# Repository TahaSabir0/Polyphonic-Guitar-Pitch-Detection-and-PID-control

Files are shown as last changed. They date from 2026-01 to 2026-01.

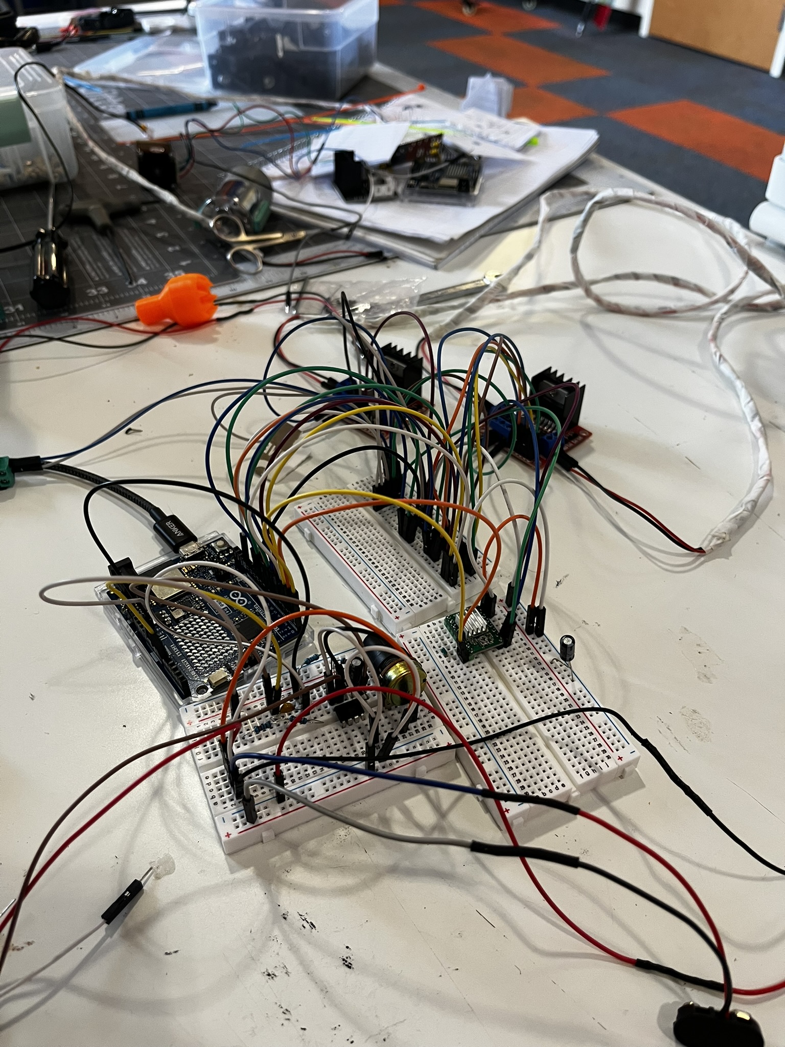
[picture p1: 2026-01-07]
hardware/system_wiring/system_wiring_1.JPEG

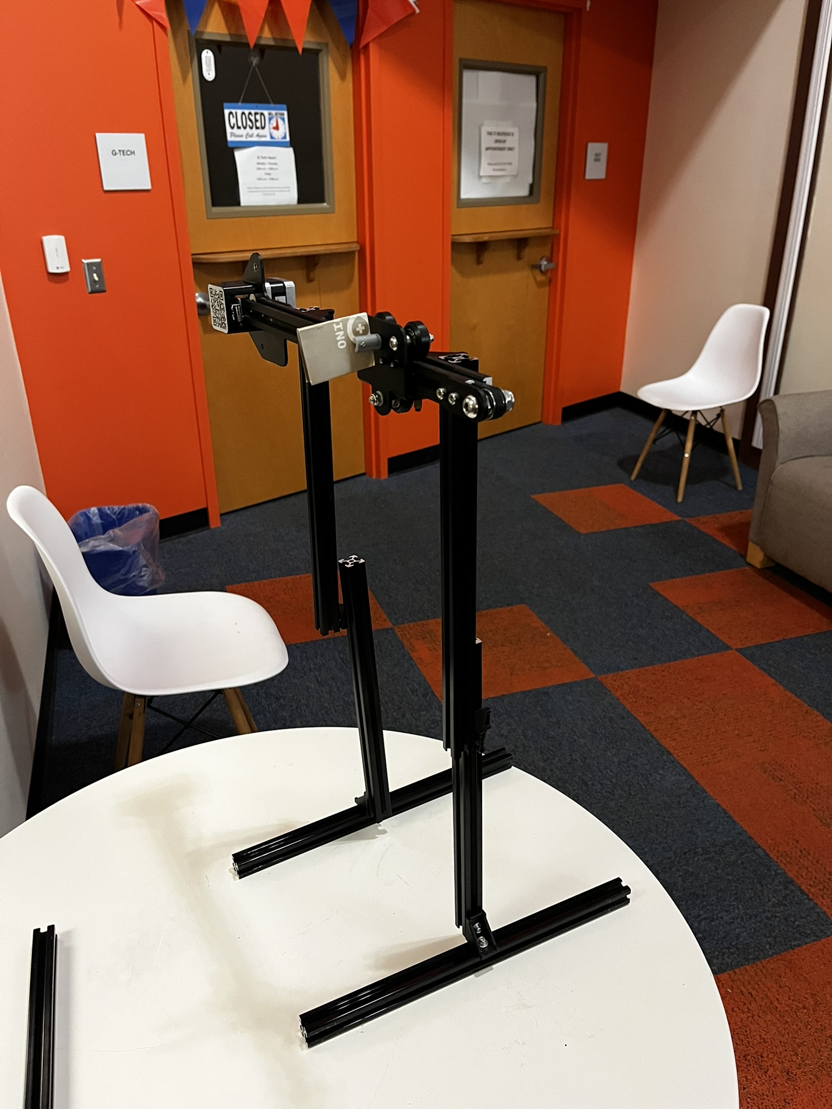
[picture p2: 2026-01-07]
hardware/individual_parts/guitar_strummer.JPEG

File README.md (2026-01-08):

# Automatic Guitar Tuning Stand

A standalone robotic system that automatically detects pitch and tunes guitar strings with precision. This project combines digital signal processing, motor control, and custom mechanical design to create a practical tool for musicians.

**Author:** Taha Sabir
**Institution:** Gettysburg College
**Program:** Digital Technology Summer Fellowship (DTSF) 2025

Watch the Demo (https://www.youtube.com/watch?v=YejNIvxSDlA)

**[▶️ Watch the Full Demo Video](https://www.youtube.com/watch?v=YejNIvxSDlA)**

---

## Table of Contents

- [Introduction](#introduction)
- [Hardware & Circuits](#hardware--circuits)
  - [Audio Detection Circuit](#1-audio-detection-circuit)
  - [Automatic Strummer](#2-automatic-strummer)
  - [Motor Selection & Tuning Mechanisms](#3-motor-selection--tuning-mechanisms)
- [Software](#software)
  - [FFT-Based Pitch Detection](#fft-based-pitch-detection)
  - [PID Control System](#pid-control-system)
  - [Code Overview](#code-overview)
- [Getting Started](#getting-started)
- [Future Improvements](#future-improvements)
- [Acknowledgements](#acknowledgements)
- [References](#references)

---

## Introduction

This repository is the guide I wish I had while building this project. Whether you're looking to replicate this automatic guitar tuning stand or create something even better, I'll walk you through every component, circuit, and line of code that makes it work.

The system consists of three fundamental subsystems working together:

1. **Audio Detection** - Captures and analyzes string vibrations to determine pitch
2. **Tuning Mechanisms** - DC motors that physically turn the tuning pegs
3. **Automatic Strummer** - A motorized slider that strums strings for polyphonic tuning

Depending on your goals, you can build any combination of these systems. Want just pitch detection? Build the audio circuit. Need a single-string tuner? Add one motor. This modular design lets you scale the project to your needs.

---

## Hardware & Circuits

### 1. Audio Detection Circuit

The audio detection system is the foundation of the project. It captures string vibrations and amplifies them for the Arduino to analyze.

#### Components

- **Microphone:** [Korg CM200BK](https://www.korg.com/us/products/tuners/cm_200/) clip-on contact microphone

  - The reason for choosing this microphone is that it picks up vibrations directly from the guitar body, eliminating ambient noise. Inspired by [Antonio Hinojosa Cabrera's work](https://upcommons.upc.edu/entities/publication/d1f17706-ed6d-4329-bab4-19746a667733).

- **Amplification Circuit:** Based on [Amanda Ghassaei's Arduino Audio Input circuit](https://www.instructables.com/Arduino-Audio-Input/)
  - Uses TL072CN operational amplifiers
  - All required components listed in Amanda's tutorial

#### Critical Modification

After weeks of debugging a signal degradation issue, I discovered that piezoelectric microphones require a DC bias path. **Add a 1 MΩ resistor** between the non-inverting input (+) of the op-amp and Arduino ground. Without this, the piezo element acts like a capacitor and slowly charges, causing the signal to fade.

**Circuit diagram:** [hardware/system_wiring/sound_amplification circuit_by_amanda_ghassaei.png](hardware/system_wiring/sound_amplification_circuit_by_amanda_ghassaei.png)

**Detailed breakdown:** [Week 3 Blog Post](https://dtsf.sites.gettysburg.edu/dtsf2025/uncategorized/week-3-algorithmic-pivots-torque-troubles-and-a-breakthrough/)

---

### 2. Automatic Strummer

For polyphonic pitch detection (tuning multiple strings simultaneously), you need to strum all strings at once. The automatic strummer handles this.

#### Components

- **Motor:** NEMA 17 stepper motor (doesn't require high torque)
- **Driver:** A4988 stepper motor driver
- **Linear Slide:** Salvaged from a 3D printer (any linear motion system works)
- **Pick Attachment:** [hardware/3D_sketches/slider_attachment.stl](hardware/3D_sketches/slider_attachment.stl)

#### Key Insight

Initial tests with a rigid 3D-printed pick produced too much string attack noise, interfering with FFT accuracy. **Solution:** Replace the plastic pick with a small piece of cardboard for a gentler, more natural strum that produces cleaner frequency data.

#### Circuit & Tutorial

Follow [Rachel De Barros' excellent stepper motor tutorial](https://www.youtube.com/watch?v=wcLeXXATCR4) for wiring the NEMA 17 with the A4988 driver.

**Circuit diagram:** [hardware/individual_parts/guitar_strummer_circuit.JPEG](hardware/individual_parts/guitar_strummer_circuit.JPEG)

---

### 3. Motor Selection & Tuning Mechanisms

This is the most critical hardware decision in the project.

#### Understanding Torque Requirements

The biggest challenge in automatic guitar tuning is motor torque. Through extensive testing with a DIY torque meter, I determined that acoustic guitar tuning pegs require approximately **0.3 N·m of dynamic torque** for the heaviest strings.

**Important distinction:** Static (holding) torque ≠ Dynamic (moving) torque. A stepper motor rated for 0.4 N·m static torque will only deliver about 40-60% of that while moving, which explains why the NEMA 17 (0.4 N·m static) couldn't handle acoustic guitar strings. ([Source](https://www.sciencedirect.com/topics/engineering/static-torque))

#### Motor Options

**Stepper Motors:**

- **Pros:** Precise control, easy to program, no gearbox needed
- **Cons:** More expensive, larger size relative to torque, dynamic torque drops significantly
- **Best for:** Single-string systems, electric guitars, lower-tension instruments
- **Recommendation:** NEMA 23 for acoustic guitars ([Auburn University reference project](https://www.youtube.com/watch?v=DU2-K5PHwyM&t=147s))

**DC Motors:**

- **Pros:** Higher torque-to-size ratio, cheaper, abundant gearbox options
- **Cons:** Less precise, more complex control
- **Best for:** Multi-string systems where space is constrained
- **Recommendation:** [Greartisan DC 12V 20RPM 37mm Gearmotor](https://www.amazon.com) (0.3+ N·m dynamic torque)

#### Why I Chose DC Motors

For a 6-string system with automatic strumming, motor size is crucial. The 37mm diameter of the Greartisan motors is the maximum that fits between guitar tuning pegs. Anything larger wouldn't work.

#### Mechanical Components

**3D Models:**

- **Motor enclosure:** [hardware/3D_sketches/motor_box.stl](hardware/3D_sketches/motor_box.stl)
- **Motor side holders:** [hardware/3D_sketches/motor_sideholder.stl](hardware/3D_sketches/motor_sideholder.stl) (prevents rotation inside enclosure)
- **DC motor peg attachment:** [hardware/3D_sketches/DC_peg_attachement.stl](hardware/3D_sketches/DC_peg_attachement.stl)
- **Stepper motor peg attachment:** [hardware/3D_sketches/stepper_peg_attachement.stl](hardware/3D_sketches/stepper_peg_attachement.stl)

**Motor Drivers:**

- **For DC motors:** L298N dual H-bridge motor drivers (can control 2 motors per driver)
- **For stepper motors:** A4988 or similar stepper driver

**Circuit diagrams:**

- [hardware/individual_parts/PID_control_circuit.JPEG](hardware/individual_parts/PID_control_circuit.JPEG)
- [hardware/system_wiring/](hardware/system_wiring/) folder contains complete system wiring photos

#### Critical Power Architecture Insight

**Problem:** Running the NEMA 17 strummer and audio circuit from the same 5V rail introduced electrical noise that disrupted the sensitive amplifier.

**Solution:** The L298N drivers have built-in 5V regulators! Power the entire system from a single 12V source:

- 12V feeds the L298N drivers (for DC motors)
- L298N's 5V output powers the Arduino
- A separate 5V source powers the audio circuit (isolated from motor noise)

This architecture eliminates electrical interference while simplifying the overall power system.

---

## Software

All code is written for the **Arduino Uno R4 WiFi** and is located in the [software/](software/) directory.

### FFT-Based Pitch Detection

After attempting autocorrelation methods (YIN algorithm), I pivoted to Fast Fourier Transform (FFT) for pitch detection. FFT converts time-domain audio signals into frequency-domain data, revealing the fundamental frequency of each string.

#### How It Works

1. **Signal Acquisition:** Sample audio at 4000 Hz with 1024 samples
2. **Windowing:** Apply Hamming window to reduce spectral leakage
3. **FFT Computation:** Transform time-domain signal to frequency spectrum
4. **Peak Detection:** For each string's frequency band (e.g., ±20 Hz around 82.41 Hz for low E), find the peak magnitude
5. **Quadratic Interpolation:** Refine frequency estimate using neighboring bins
6. **Filtering:** Apply SNR (signal-to-noise ratio) and magnitude thresholds to reject noise

#### Critical Discovery: Clock Drift

The Arduino R4 uses two internal clock sources:

- **USB-PLL:** Highly accurate when connected to a computer
- **HOCO:** Less accurate, temperature-sensitive clock when running standalone

My board's HOCO clock ran 2.5% fast, causing all frequency readings to be 2.5% too high. This explained why the system worked perfectly when connected to my laptop but failed when running on battery power. The solution was to measure the actual sampling rate during runtime and compensate accordingly.

**Implementation:** [software/six_string_FFT.ino:217-218](software/six_string_FFT.ino)

### PID Control System

PID (Proportional-Integral-Derivative) control optimally adjusts motor movements based on pitch error.

#### The Formula

```
control_output = Kp × error + Ki × ∫error dt + Kd × d(error)/dt
```

- **Kp (Proportional):** Immediate response proportional to error magnitude
- **Ki (Integral):** Corrects accumulated error over time
- **Kd (Derivative):** Dampens oscillations by considering rate of change

#### Tuning Constants

After extensive calibration:

- `Kp = 1.2`
- `Ki = 9.0`
- `Kd = 0.0` (derivative not needed for this application)

The error is calculated in **cents** (1 cent = 1/100th of a semitone) for musical accuracy:

```cpp
float cents = 1200.0f * log2f(targetFreq / measuredFreq);
```

The PID output is then clamped to ±20 units and mapped to motor burst durations (250-900 ms), preventing excessive overshooting.

**Implementation:** [software/Three_Strings_Final_Demo.ino:269-274](software/Three_Strings_Final_Demo.ino)

### Code Overview

#### [single_string_stepper.ino](software/single_string_stepper.ino)

**Purpose:** Tune a single string using a stepper motor
**Features:**

- FFT pitch detection (1024 samples @ 4000 Hz)
- PID control with integral wind-up prevention
- 0.6-second hold filter (rejects transient noise)
- Precision: ±1 cent tolerance

**Key functions:**

- `detectFundamental()`: Captures audio, performs FFT, returns frequency
- `pidDelta()`: Calculates motor steps needed based on pitch error
- `stepperStepBlocking()`: Executes precise stepper movements

---

#### [single_string_DC.ino](software/single_string_DC.ino)

**Purpose:** Tune a single string using a DC motor
**Features:**

- Identical FFT and PID logic to stepper version
- Burst-based motor control (maps PID output to timed motor pulses)
- Configurable direction sense (`DIR_SIGN`) for different tuning peg orientations

**Key differences from stepper:**

- `motorDrive()`: Sends PWM bursts instead of precise steps
- Faster tuning but less granular control

---

#### [six_string_FFT.ino](software/six_string_FFT.ino)

**Purpose:** Monitor and detect pitch for all six strings simultaneously
**Features:**

- Polyphonic pitch detection using frequency binning
- Individual SNR and magnitude thresholds per string
- Automatic strumming integration

**How polyphonic detection works:**
The FFT spectrum is divided into six non-overlapping frequency windows centered on standard tuning:

| String | Frequency | Detection Band |
| --- | --- | --- |
| E2 | 82.41 Hz  | 62-102 Hz |
| A2 | 110.00 Hz | 90-130 Hz |
| D3 | 146.83 Hz | 127-167 Hz |
| G3 | 196.00 Hz | 176-216 Hz |
| B3 | 246.94 Hz | 227-267 Hz |
| E4 | 329.63 Hz | 310-350 Hz |

Each band's peak is tracked independently, allowing simultaneous tuning of multiple strings.

**Challenge: Sympathetic Resonance**

When all strings are strummed together, harmonics from heavy strings interfere with lighter strings. For example, the 3rd harmonic of A2 (110 Hz) is 330 Hz, which overlaps with E4's fundamental (329.63 Hz). This required carefully tuned SNR thresholds and magnitude gates per string.

---

#### [Three_Strings_Final_Demo.ino](software/Three_Strings_Final_Demo.ino) ⭐

**Purpose:** Complete working prototype - automatically tunes three strings
**Features:**

- Integrated strumming, FFT detection, and concurrent motor control
- Median filtering (collects 0.2s of data, uses median frequency)
- Concurrent motor bursts (all three motors can move simultaneously)
- 4-second cycle period (strum → detect → tune → repeat)

**Control loop:**

1. Strum strings back and forth (2 seconds total movement)
2. Wait 0.2 seconds for string attack to settle
3. Collect FFT data for 0.2 seconds
4. Calculate median frequency for each string
5. Apply PID control and execute motor bursts concurrently
6. Check if all strings are within ±1 Hz tolerance
7. Repeat until tuned

**Why concurrent bursts?**
Motors operate simultaneously, dramatically reducing tuning time. Each motor independently calculates its burst duration based on PID output.

**Implementation highlights:**

- `startBurst()`: Initiates non-blocking motor movement
- `waitBursts()`: Polls motors until all complete
- `track()`: Per-string FFT peak detection with quadratic interpolation
- `median()`: Robust frequency estimation over multiple frames

---

## Getting Started

### Prerequisites

**Hardware:**

- Arduino Uno R4 WiFi (or Mega for 6-string system)
- Audio detection circuit components (see Hardware section)
- Motors (stepper or DC) based on your application
- Motor drivers (A4988 for stepper, L298N for DC)
- 12V power supply
- 3D printer for mechanical components

**Software:**

- [Arduino IDE](https://www.arduino.cc/en/software)
- [ArduinoFFT library](https://github.com/kosme/arduinoFFT)

### Assembly Steps

1. **Build the audio circuit** following Amanda Ghassaei's tutorial with the 1 MΩ resistor modification
2. **3D print mechanical components** from [hardware/3D_sketches/](hardware/3D_sketches/)
3. **Wire motors and drivers** using circuit diagrams in [hardware/individual_parts/](hardware/individual_parts/)
4. **Upload appropriate sketch** from [software/](software/) directory
5. **Calibrate** by adjusting FFT thresholds and PID gains for your specific guitar

### Quick Start: Single-String Tuner

For your first build, I recommend starting with the single-string stepper motor version:

1. Build the audio detection circuit
2. Connect a NEMA 17 motor with A4988 driver
3. Upload [single_string_stepper.ino](software/single_string_stepper.ino)
4. Adjust `TARGET_FREQ` to your desired string
5. Manually strum the string and watch it tune automatically!

---

## Future Improvements

This project has immense potential for expansion. Here are ideas for taking it further:

### 1. Comprehensive Torque Study

String instrument tuning torque requirements are severely under-documented in academic literature. A systematic study measuring torque across different instruments, string gauges, and materials would be invaluable for future automatic tuner designs.

### 2. Complete 6-String System

Due to time and budget constraints, I built a 3-string prototype. The complete vision involves:

- Two 3-motor modules (one fixed, one spring-loaded)
- Adjustable phone holder-style mechanism
- Clamps onto all six tuning pegs simultaneously
- Single-button operation

### 3. Linear Regression Tuning

The current system uses iterative "burst" adjustments. A smarter approach:

- Calibrate the relationship between motor rotation and pitch change for each string
- Use linear regression to predict exact motor movement needed
- Achieve perfect tuning in a single movement (~3 seconds total)

### 4. User Interface

Build a proper interface with:

- LCD display showing current pitch vs. target
- Tuning preset selection (standard, drop D, open G, etc.)
- Calibration buttons
- Status LEDs

### 5. Automatic FFT Calibration

Currently, FFT variables (SNR thresholds, magnitude gates, bin widths) require manual tweaking for hours. An automatic calibration protocol that adapts to different guitars would make the system truly universal.

### 6. Hybrid Initialization System

Current limitation: The polyphonic binning model only works if strings are initially close to the correct tuning. A robust solution:

- **Phase 1:** Individual string calibration (strum each string separately with high-precision strummer)
- **Phase 2:** Once all strings are within their bins, switch to concurrent tuning mode
- Combined with a good UI, this creates the blueprint for a commercializable product

---

## Acknowledgements

This project was sparked by [Tim Bell's 2011 automatic guitar tuner video](https://www.youtube.com/watch?v=ZahpROn3gm0), which proved this was possible to build. That single video flicked a switch in my mind and set me on this journey.

None of this would have been possible without the invaluable guidance and unwavering support of **Professor Eric Remy** and **Joshua Wagner**. Their mentorship through every challenge, from fried op-amps to motor torque mysteries, was instrumental in bringing this project to life.

---

## References

### Academic Papers

- Gylling, Martin, and Ruben Svensson. "Robotic Electric Guitar Tuner." Bachelor's thesis, 2020.
- Hinojosa Cabrera, Antonio. "Automatic Guitar Tuner." Bachelor's thesis, Universitat Politècnica de Catalunya, 2020. [Link](https://upcommons.upc.edu/entities/publication/d1f17706-ed6d-4329-bab4-19746a667733)
- Boestad, Erik, and Rudberg, Johan. "Piezoelectric Guitar Tuner." Research paper.

### Tutorials & Resources

- [Amanda Ghassaei - Arduino Audio Input](https://www.instructables.com/Arduino-Audio-Input/)
- [Rachel De Barros - Stepper Motor Control](https://www.youtube.com/watch?v=wcLeXXATCR4)
- [Auburn University MECH 5840 - Automatic Guitar Tuner](https://www.youtube.com/watch?v=DU2-K5PHwyM&t=147s)
- [ScienceDirect - Static vs Dynamic Torque](https://www.sciencedirect.com/topics/engineering/static-torque)

### Project Blog

For a week-by-week chronicle of the development process, including all the failures, breakthroughs, and lessons learned, visit:
[DTSF 2025 - Automatic Guitar Tuning Stand Blog](https://dtsf.sites.gettysburg.edu/dtsf2025/taha)

---

**Happy building! If you create your own version or make improvements, I'd love to hear about it.**

_This project was completed as part of the Digital Technology Summer Fellowship (DTSF) at Gettysburg College, Summer 2025._

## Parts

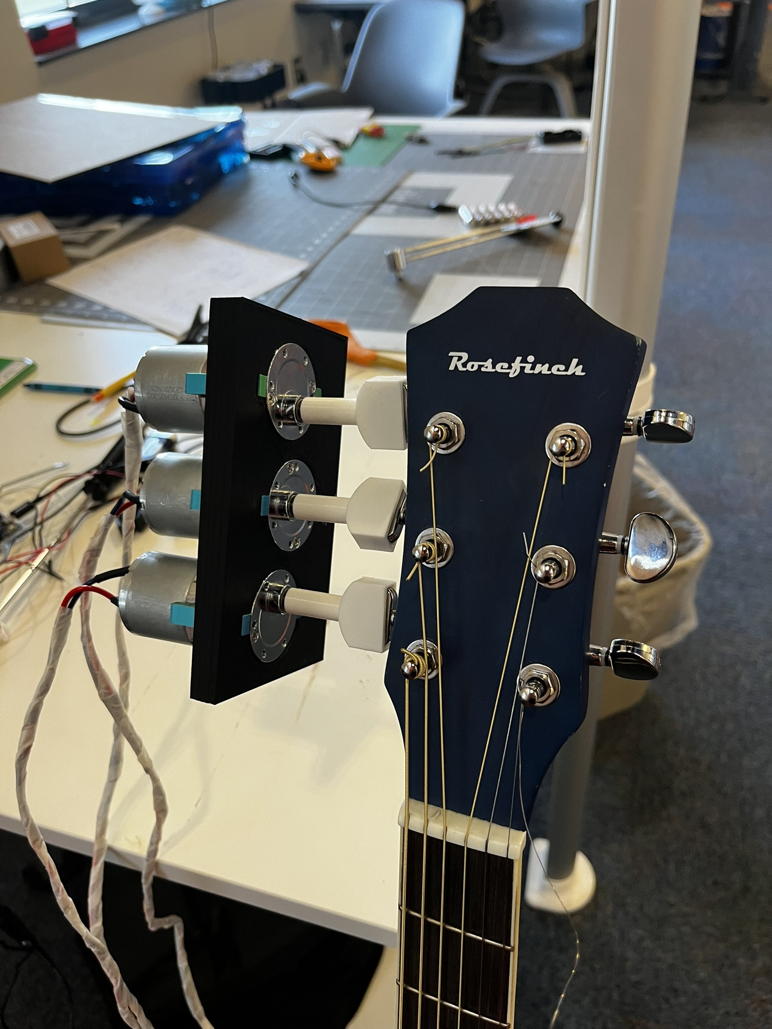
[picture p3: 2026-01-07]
hardware/individual_parts/motors_attachement.JPEG

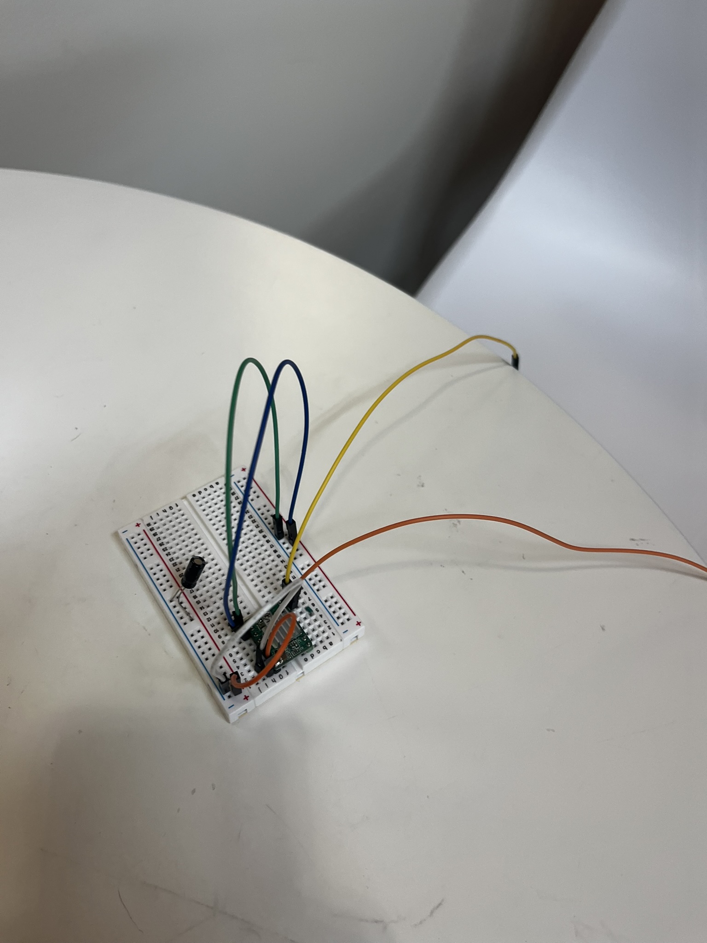
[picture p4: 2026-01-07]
hardware/individual_parts/guitar_strummer_circuit.JPEG

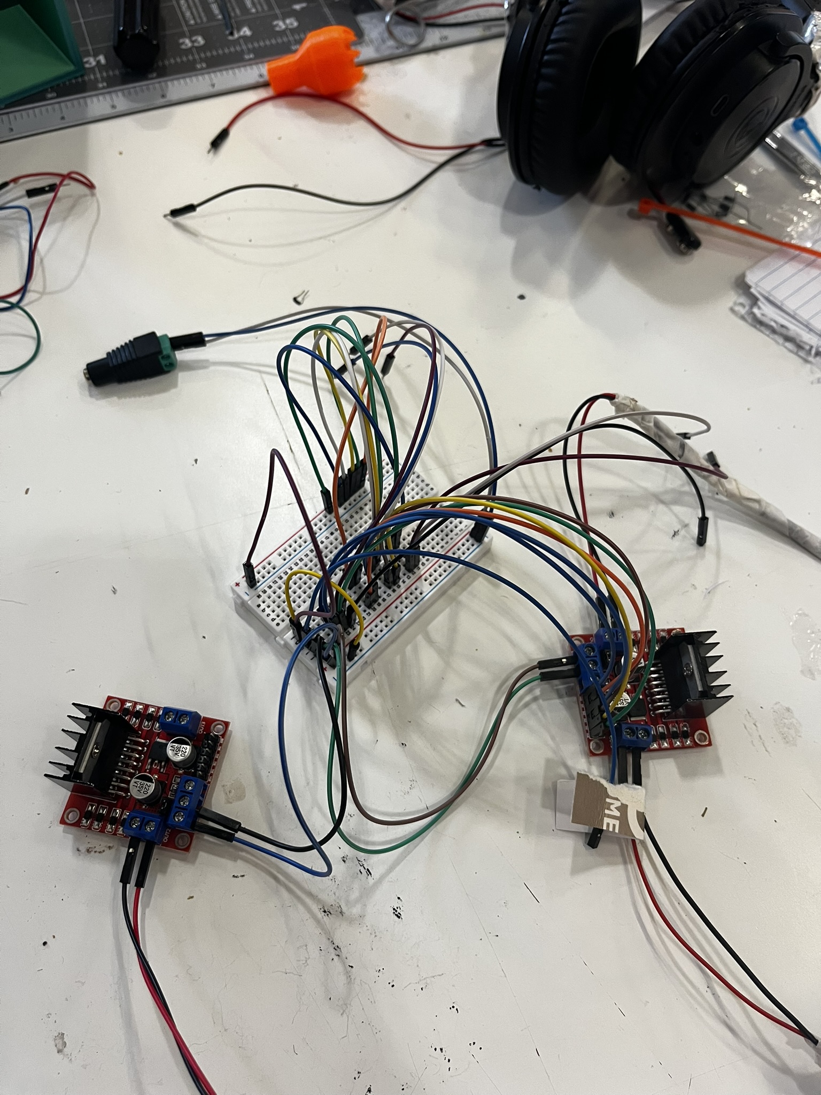
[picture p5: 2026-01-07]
hardware/individual_parts/PID_control_circuit.JPEG

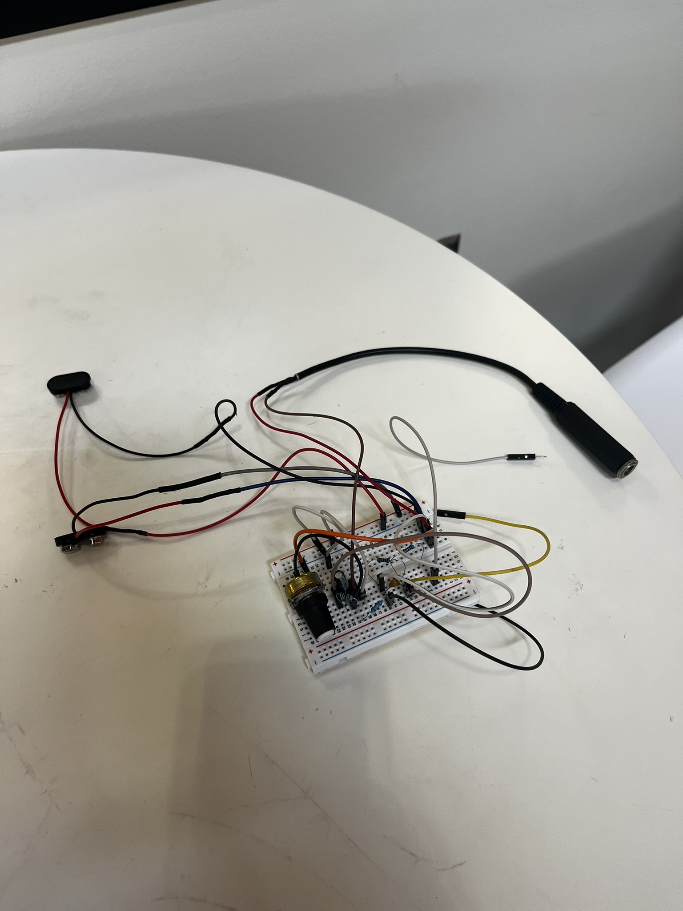
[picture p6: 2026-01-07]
hardware/individual_parts/audio_amplificator_circuit.JPEG

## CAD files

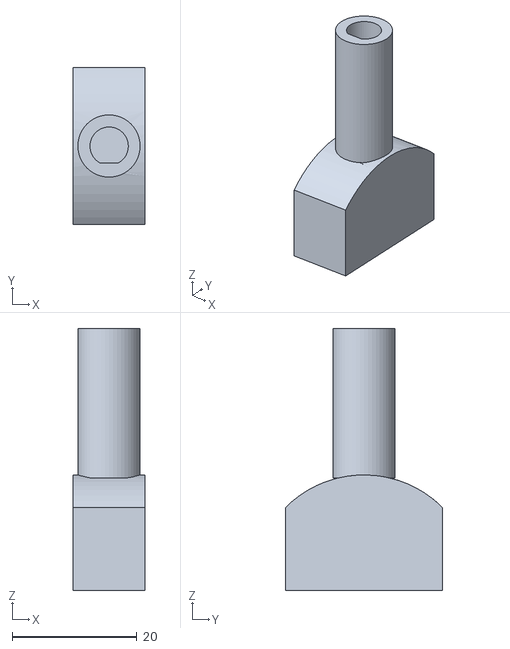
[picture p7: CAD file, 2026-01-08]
hardware/3D_sketches/DC_peg_attachement.stl
11.5 x 25.2 x 42.1

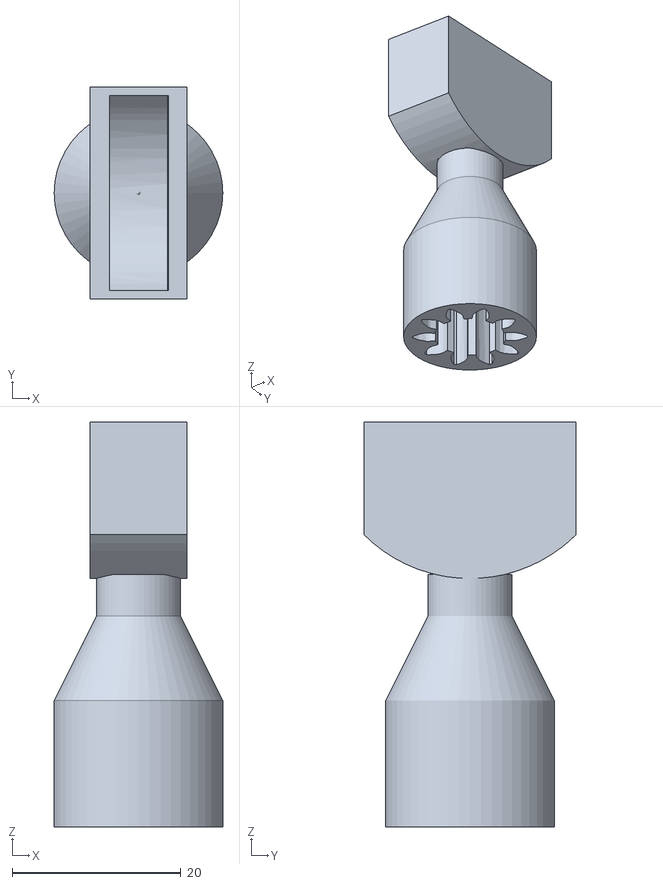
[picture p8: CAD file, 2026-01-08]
hardware/3D_sketches/stepper_peg_attachement.stl
20.0 x 25.2 x 48.0

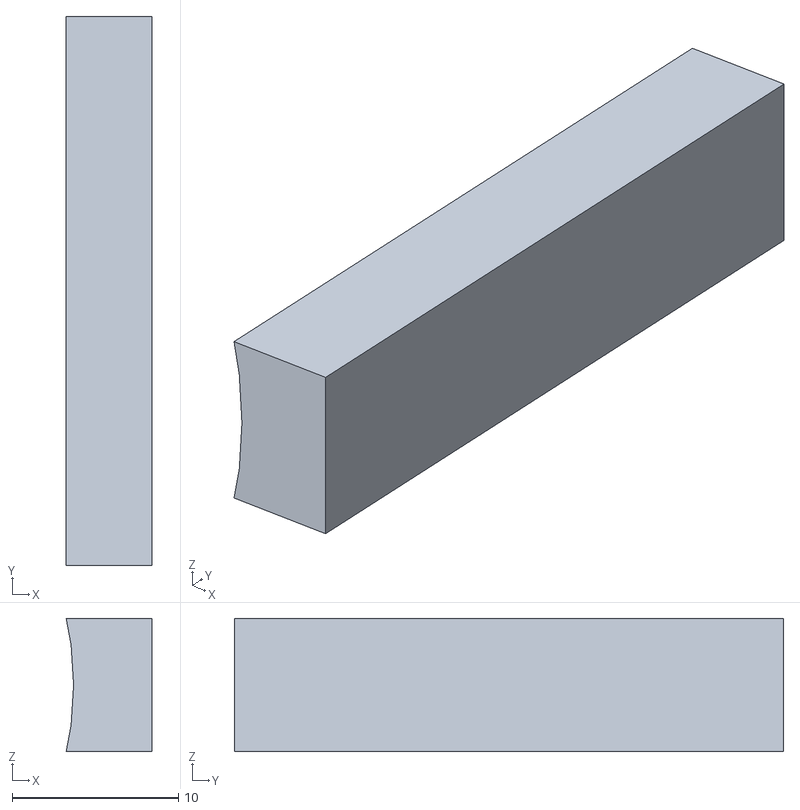
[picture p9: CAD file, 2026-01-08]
hardware/3D_sketches/motor_sideholder.stl
5.15 x 33.0 x 8.00

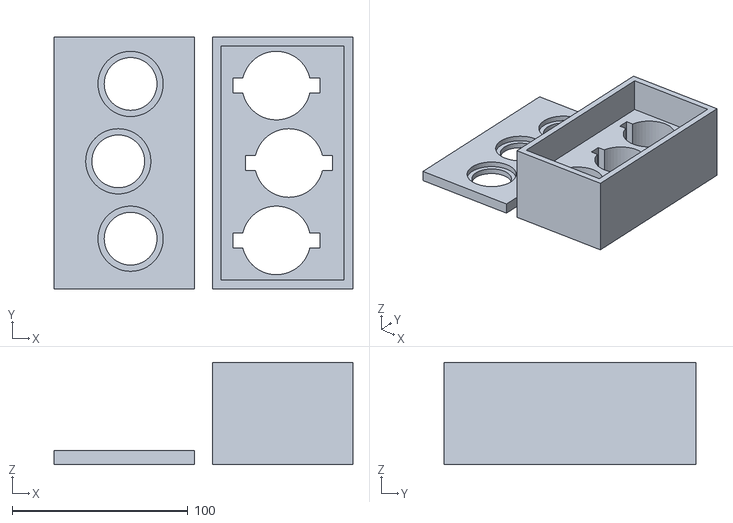
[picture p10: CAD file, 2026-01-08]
hardware/3D_sketches/motor_box.stl
170.0 x 143.0 x 58.0

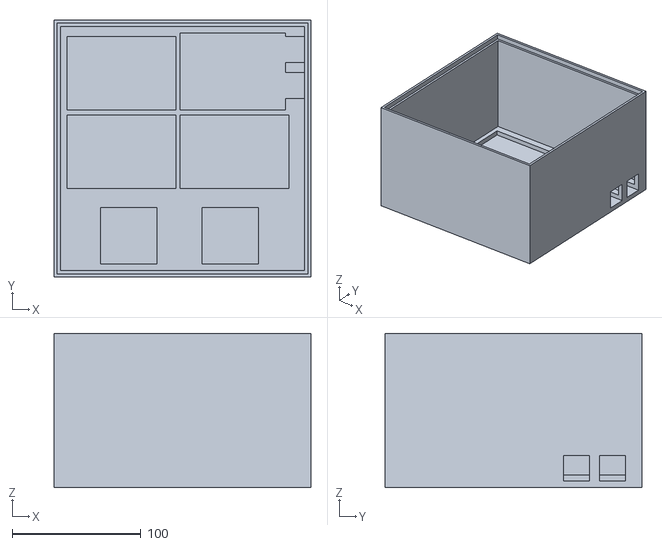
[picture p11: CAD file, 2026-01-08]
hardware/3D_sketches/Electronics_box.stl
200.0 x 200.0 x 120.0

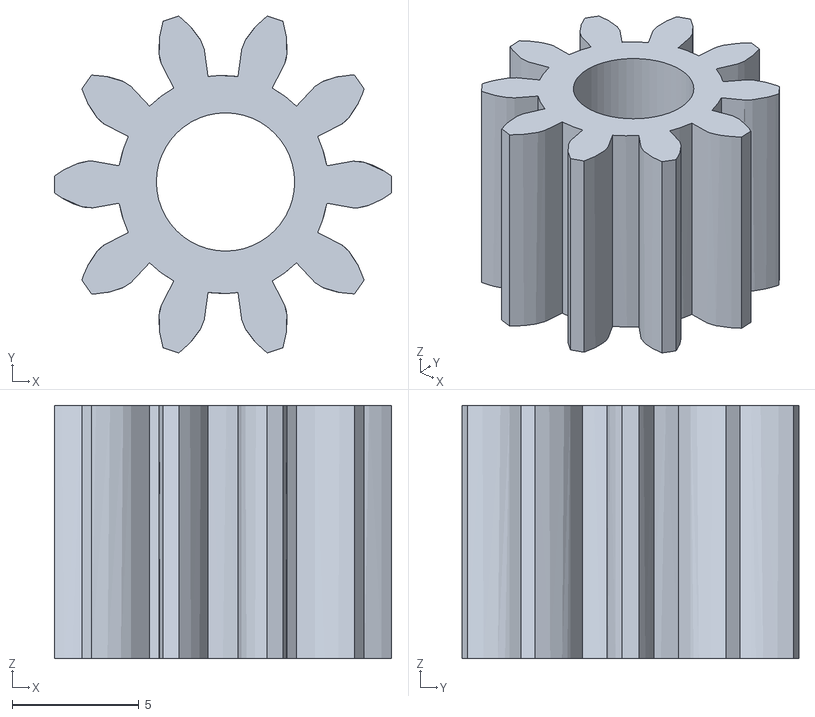
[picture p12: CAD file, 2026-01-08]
hardware/3D_sketches/stepper_gear.stl
13.3 x 13.3 x 10.0

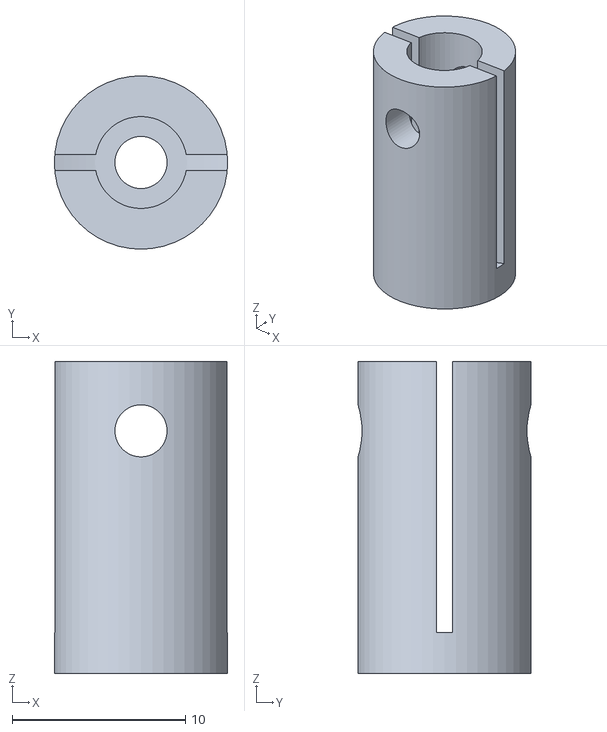
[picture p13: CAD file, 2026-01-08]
hardware/3D_sketches/slider_attachment.stl
10.0 x 10.0 x 18.0

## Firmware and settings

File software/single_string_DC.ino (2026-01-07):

/*********************************************************************
 * Purpose: Single-string tuning with a DC motor and PID control.
 * Board: Arduino Uno R4
 * Description: This sketch will tune a single guitar string using a
 * DC motor with an encoder and a PID controller for precise positioning.
 *********************************************************************/

#include <Arduino.h>
#include <arduinoFFT.h>
#include <algorithm>                 // std::nth_element


/*──────── USER CONSTANTS ───────*/
constexpr uint16_t FFT_SAMPLES   = 1024;
constexpr float    FS_HZ         = 4000.0f;
constexpr uint8_t  ADC_PIN       = A0;
constexpr float    DC_OFFSET     = 517.0f;      // bias midpoint (10-bit)


/* Signal-quality guards */
constexpr float    RMS_MIN       = 8.0f;
constexpr float    MIN_SNR       = 5.0f;
constexpr uint8_t  N_STABLE      = 3;
constexpr float    STRUM_GATE    = 250.0f;


/* Search band */
constexpr float    FREQ_MIN_HZ   =  50.0f;
constexpr float    FREQ_MAX_HZ   = 400.0f;


/* Target (set per string before tuning) */
constexpr float    TARGET_FREQ   = 82.41f;     // high-E
constexpr float    CENT_TOL      = 0.30f;


/* PID gains */
constexpr float    Kp = 1.2f, Ki = 9.0f, Kd = 0.0f;
constexpr float    STEP_SCALE    = 1.2f;
constexpr int32_t  STEP_CLAMP    = 15;


/* ── DC-motor / L298N wiring ── */
constexpr uint8_t  M_IN1   = 2;
constexpr uint8_t  M_IN2   = 3;
constexpr uint8_t  M_PWM   = 9;
constexpr uint8_t  MAX_PWM = 255;     // full duty


/* Burst timing (maps 1…15 proxy-steps → 250…900 ms) */
constexpr uint16_t MIN_BURST_MS = 250;
constexpr uint16_t MAX_BURST_MS = 900;


/*  Direction sense  ------------------------------------------------
    DIR_SIGN = +1  → positive proxy-steps tighten (clockwise peg)
    DIR_SIGN = −1  → positive proxy-steps loosen  (flip motor sense)


    Set to −1 for strings whose tuners tighten in the opposite direction.
   ------------------------------------------------------------------*/
constexpr int8_t   DIR_SIGN = -1;     // change to −1 for reversed pegs


/*──────── BUFFERS ───────*/
float vRe[FFT_SAMPLES], vIm[FFT_SAMPLES];
ArduinoFFT<float> FFT(vRe, vIm, FFT_SAMPLES, FS_HZ);
static float mags[FFT_SAMPLES/2];


const uint32_t SAMPLE_PERIOD_US = 1'000'000UL / uint32_t(FS_HZ);


/* PID / state */
float pidI = 0, lastErrHz = 0;
float lastPeakMag = 0, lastGoodFreq = 0;
uint8_t stableFrames = 0;


/* 0.4-s hold filter */
float    holdRefHz     = 0;
uint32_t holdStartMs   = 0;
bool     freqConfirmed = false;


/*──────── DC-MOTOR HELPER ───────*/
void motorDrive(int32_t proxySteps)
{
  if (!proxySteps) return;                            // nothing to do


  int32_t signedSteps = proxySteps * DIR_SIGN;        // flip if needed
  bool tighten = signedSteps > 0;                     // final direction


  uint16_t burst = map(abs(signedSteps),
                       1, STEP_CLAMP,
                       MIN_BURST_MS, MAX_BURST_MS);


  digitalWrite(M_IN1, tighten ? HIGH : LOW);
  digitalWrite(M_IN2, tighten ? LOW  : HIGH);


  analogWrite(M_PWM, MAX_PWM);
  delay(burst);
  analogWrite(M_PWM, 0);                              // stop
}


/*──────── FFT FUNDAMENTAL DETECTOR ───────*/
float detectFundamental()
{
  uint32_t tNext = micros();
  float rmsSq = 0;
  for (uint16_t i = 0; i < FFT_SAMPLES; ++i) {
    while (micros() < tNext) {}
    float s = analogRead(ADC_PIN) - DC_OFFSET;
    vRe[i] = s;  vIm[i] = 0;  rmsSq += s * s;
    tNext += SAMPLE_PERIOD_US;
  }
  if (sqrtf(rmsSq / FFT_SAMPLES) < RMS_MIN) { lastPeakMag = 0; return -1; }


  FFT.windowing(FFTWindow::Hamming, FFTDirection::Forward);
  FFT.compute   (FFTDirection::Forward);
  FFT.complexToMagnitude();


  const float BIN_HZ = FS_HZ / FFT_SAMPLES;
  uint16_t kL = max<uint16_t>(1, ceil (FREQ_MIN_HZ / BIN_HZ));
  uint16_t kH = min<uint16_t>(FFT_SAMPLES/2-1, floor(FREQ_MAX_HZ / BIN_HZ));


  uint16_t n = 0;
  for (uint16_t k = kL; k <= kH; ++k) mags[n++] = vRe[k];
  std::nth_element(mags, mags + n/2, mags + n);
  float floorMag = mags[n/2];


  float pk = 0; uint16_t bin = 0;
  for (uint16_t k = kL; k <= kH; ++k)
    if (vRe[k] > pk) { pk = vRe[k]; bin = k; }
  if (pk < MIN_SNR * floorMag) return -1;
  lastPeakMag = pk;


  float f = bin * BIN_HZ;
  if (bin > 0 && bin < FFT_SAMPLES/2 - 1) {
    float m1 = vRe[bin-1], m2 = pk, m3 = vRe[bin+1];
    float d  = 2.0f * (2.0f*m2 - m1 - m3);
    float off = d ? (m3 - m1) / d : 0;
    f = (bin + off) * BIN_HZ;
  }
  return f;
}


/*──────── PID → proxy-step (signed) ───────*/
int32_t pidProxy(float f)
{
  float errHz = TARGET_FREQ - f;
  float cent  = 1200.0f * log2f(TARGET_FREQ / f);
  if (fabsf(cent) < CENT_TOL) { pidI = 0; return 0; }


  pidI += errHz / FS_HZ;
  float pid = Kp*errHz + Ki*pidI + Kd*(errHz - lastErrHz)*FS_HZ;
  lastErrHz = errHz;


  int32_t s = int32_t(cent * STEP_SCALE);
  return constrain(s, -STEP_CLAMP, STEP_CLAMP);
}


/*──────── SETUP ───────*/
void setup()
{
  pinMode(M_IN1, OUTPUT);
  pinMode(M_IN2, OUTPUT);
  pinMode(M_PWM, OUTPUT);
  analogWrite(M_PWM, 0);


  analogReadResolution(10);


  Serial.begin(115200);
  while (!Serial) {}
  Serial.println("\nFFT tuner – DC-motor version (DIR_SIGN variable)");
}


/*──────── LOOP ───────*/
void loop()
{
  float f = detectFundamental();


  if (lastPeakMag < STRUM_GATE)               { freqConfirmed=false; return; }
  if (f < 0)                                  { freqConfirmed=false; return; }


  /* Hold filter: ±10 Hz for ≥0.4 s */
  uint32_t now = millis();
  if (!freqConfirmed) {
    if (holdStartMs == 0) { holdRefHz = f; holdStartMs = now; }
    else if (fabsf(f - holdRefHz) <= 10.0f) {
      if (now - holdStartMs >= 400) freqConfirmed = true;   // 0.4 s
    } else { holdRefHz = f; holdStartMs = now; }
  }


  Serial.print("Freq "); Serial.print(f, 2);
  Serial.print(" Hz  |X|max "); Serial.print(lastPeakMag, 0);


  if (!freqConfirmed) { Serial.println("  (waiting 0.4 s)"); return; }


  /* Stability gate */
  if (lastGoodFreq>0 && fabsf(f-lastGoodFreq)/f < 0.01f) {
    if (++stableFrames < N_STABLE) return;
  } else stableFrames = 1;
  lastGoodFreq = f;


  int32_t proxy = pidProxy(f);
  if (proxy) {
    motorDrive(proxy);
    Serial.print("  burst "); Serial.print(proxy); Serial.println();
  } else {
    Serial.println("  in-tune ✔");
  }
}

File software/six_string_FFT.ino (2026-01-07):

/*********************************************************************
 * Purpose: Monitor all six strings and measure fundamental frequency.
 * Board: Arduino Uno R4
 * Description: This sketch will monitor all six strings, detect which
 * one is played, and measure its fundamental frequency using FFT.
 *********************************************************************/


#include <Arduino.h>
#include <arduinoFFT.h>
#include <algorithm>




/* ---------- fixed FFT length ---------- */
constexpr uint16_t FFT_N = 1024;




/* ---------- analogue front-end ---------- */
constexpr uint8_t  ADC_PIN = A0;
constexpr float    DC_OFF  = 505.0f;      // bias midpoint
constexpr float    RMS_MIN = 8.0f;        // frame-level floor




/* ---------- per-string tunables ---------- */
struct StringTun {
  const char *name;
  float targetHz;
  float bandHalfHz;
  float minSNR;
  float minMag;
};




/* your new table */
StringTun STR[6] = {
/* name  Hz      band  SNR   mag */
 {"E2",  82.41f, 20,   5.0f,  500},
 {"A2", 110.00f, 20,   4.0f,  400},
 {"D3", 146.83f, 20,   3.0f,  300},
 {"G3", 196.00f, 20,   2.0f,  500},
 {"B3", 246.94f, 20,   3.0f,  200},
 {"E4", 329.63f, 20,   2.0f,  120}
};




/* ---------- FFT buffers ---------- */
float vRe[FFT_N], vIm[FFT_N];
ArduinoFFT<float> FFT(vRe, vIm, FFT_N, 4000.0f);   // Fs placeholder
static float mags[FFT_N/2];




/* ---------- helper: track one string ---------- */
float trackString(const float *spec,
                  const StringTun &st,
                  float binHz)              // actual Fs / 1024
{
  int kC = int(round(st.targetHz / binHz));
  int kL = max(1, kC - int(st.bandHalfHz / binHz));
  int kH = min(int(FFT_N/2-1), kC + int(st.bandHalfHz / binHz));




  /* median floor */
  uint16_t n=0; for(int k=kL;k<=kH;++k) mags[n++] = spec[k];
  std::nth_element(mags, mags+n/2, mags+n);
  float floorMag = mags[n/2];




  /* peak & SNR */
  float pk=0; int bin=kC;
  for(int k=kL;k<=kH;++k)
    if(spec[k] > pk){ pk = spec[k]; bin = k; }
  if(pk < st.minSNR * floorMag) return -1;
  if(pk < st.minMag)            return -1;




  /* quadratic interpolation */
  float f = bin * binHz;
  if(bin>0 && bin<FFT_N/2-1) {
    float m1=spec[bin-1], m2=pk, m3=spec[bin+1];
    float d = 2*(2*m2 - m1 - m3);
    float off = d ? (m3-m1)/d : 0;
    f = (bin + off) * binHz;
  }
  return f;
}




const uint8_t SLIDER_STEP_PIN = 0;   // STEP  ↔ driver
const uint8_t SLIDER_DIR_PIN  = 1;   // DIR   ↔ driver




/* Simple one-shot move executed in setup() */
void oneSecondStrum()                 // call this ONCE inside setup()
{
  const uint16_t PULSE_HZ = 800;               // 800 full-step pulses s-¹
  const uint16_t HALF_US  = 500000UL / PULSE_HZ;  // half-period (µs)








  pinMode(SLIDER_STEP_PIN, OUTPUT);
  pinMode(SLIDER_DIR_PIN,  OUTPUT);








  digitalWrite(SLIDER_DIR_PIN, HIGH);    // choose “strum” direction








  unsigned long t0 = millis();
  while (millis() - t0 < 1000) {         // 1 000 ms = 1 s
    digitalWrite(SLIDER_STEP_PIN, HIGH);
    delayMicroseconds(HALF_US);
    digitalWrite(SLIDER_STEP_PIN, LOW);
    delayMicroseconds(HALF_US);
  }
}




/* Simple one-second move in the opposite direction */
void oneSecondStrumOpposite()        // call this ONCE inside setup()
{
  const uint16_t PULSE_HZ = 800;                 // 800 full-step pulses /s
  const uint16_t HALF_US  = 500000UL / PULSE_HZ; // half-period (µs)




  pinMode(SLIDER_STEP_PIN, OUTPUT);
  pinMode(SLIDER_DIR_PIN,  OUTPUT);




  digitalWrite(SLIDER_DIR_PIN, LOW); // **reverse** direction




  unsigned long t0 = millis();
  while (millis() - t0 < 1000) {     // 1000 ms = 1 s
    digitalWrite(SLIDER_STEP_PIN, HIGH);
    delayMicroseconds(HALF_US);
    digitalWrite(SLIDER_STEP_PIN, LOW);
    delayMicroseconds(HALF_US);
  }
}




/* ---------- setup ---------- */
void setup()
{
  analogReadResolution(10);
  Serial.begin(115200);
  while(!Serial){}
  Serial.println("\nSix-string FFT monitor – measured Fs with tuned gates");
  oneSecondStrum();
  oneSecondStrumOpposite();
}




/* ---------- main loop ---------- */
void loop()
{
  /* 1 ── capture frame & time it */
  uint32_t t0 = micros();
  float rmsSq = 0;
  for(uint16_t i=0;i<FFT_N;++i){
    float s = analogRead(ADC_PIN) - DC_OFF;
    vRe[i] = s;  vIm[i] = 0;  rmsSq += s*s;
    delayMicroseconds(250);              // nominal 4 kHz pacing
  }
  uint32_t elapsed = micros() - t0;      // µs for 1024 samples
  if(elapsed == 0) return;               // safety
  float actualFs = 1.0e6f * FFT_N / elapsed;
  float binHz    = actualFs / FFT_N;




  if(sqrtf(rmsSq / FFT_N) < RMS_MIN) return;




  /* 2 ── FFT magnitude */
  FFT.windowing(FFTWindow::Hamming, FFTDirection::Forward);
  FFT.compute   (FFTDirection::Forward);
  FFT.complexToMagnitude();




  /* 3 ── scan & print */
  for(const auto &st : STR){
    float f = trackString(vRe, st, binHz);
    Serial.print(st.name); Serial.print(": ");
    if(f < 0) Serial.print("--");
    else { Serial.print(f,2); Serial.print(" Hz"); }
    Serial.print("   ");
  }
  Serial.println();
}

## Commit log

2026-01-08 add initial sketches for motor functionality tests and automatic guitar tuning
2026-01-08 Add new 3D sketches and update software for automatic guitar tuning functionality
    [DC peg attachement.stl, Electronics box.stl, motor box.stl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]
2026-01-08 Remove motor smoke test sketch as part of code cleanup
2026-01-08 Add new circuit diagrams and sketches for automatic guitar tuning functionality
2026-01-08 Add new 3D sketches and circuit diagrams for hardware components
    [DC_peg_attachement.stl, Electronics_box.stl, motor_box.stl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]
2026-01-08 Fix circuit diagram link in README.md for clarity
